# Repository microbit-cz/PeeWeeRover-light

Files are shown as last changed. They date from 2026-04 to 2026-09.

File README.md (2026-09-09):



# PeeWee Rover Light
Jednoduché a levné PeeWee vozítko pro Micro:bit. Jedná se o OpenHardware platformu vyvinutou pro podporu projektové výuky v předmětech jako Programování, Algoritmizace, Informatické myšlení a podobně.

Bez dalších modifikací je vozítko určeno pro programování pomocí MakeCode (Blockly / Static TypeScript) s mikrokontrolérem Micro:bit, lze jej ale snadno adaptovat i na libovolný jiný mikrokontrolér (Arduino, ESP32 atd.).

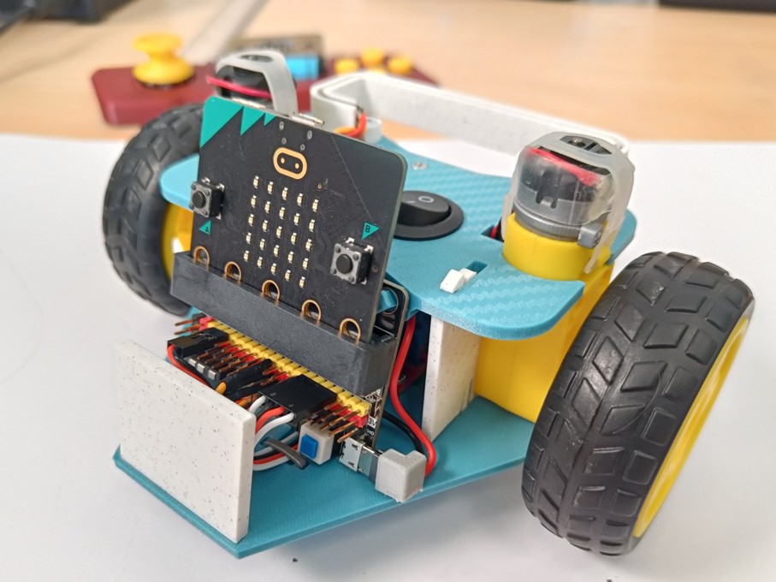
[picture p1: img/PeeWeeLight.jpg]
Foto prototypu


## O projektu
Systém je navržen s ohledem na:
- **Mechanickou robustnost**.
- **Opakovatelnost stavby:** Dražší komponenty je možné používat opakovaně. Levné položky, jako jsou 3D tištěné díly a kabely, stojí řádově desetikoruny. Další studenti tak mohou stavbu bez potíží opakovat od výchozího stavu z rozložených součástek.
- **Mezipředmětové vazby:** Ideální pro propojení oborů jako polytechnika, algoritmizace, elektrotechnika, fyzika, multimédia, matematika a další.

## Hardware a konstrukce
Základem je 3D tištěné šasi, které je osazené dvěma DC130 motory s TT převodovkou, dvěma koly a zadním vláčeným kolečkem (ocelová kulička otočná v 360°). 

Napájení je zajištěno z 2S 7,4V battery packu. Jako zdroj napájení a řízení motorů slouží modul motor driver L298N. Pro řízení logiky je použit Micro:bit připojený do desky IObit pro snadnější propojení GPIO z mikrokontroléru.

**Osvětlení (WS2812B):**
Na vozítku je připevněno celkem 9 adresovatelných RGB LED diod.
- 5 směřuje dozadu (B - Back)
- 1 směřuje vlevo (L - Left)
- 1 směřuje vpravo (R - Right)
- 2 směřují vpřed (F - Front)

Fyzické řazení diod v sérii je: **F - R - B - B - B - B - B - L - F**

## Schéma a návod ke stavbě
- **Zjednodušené schéma elektrického zapojení:** [schema.svg](schema.svg) (nebo [schema.pdf](schema.pdf))
- **Videonávod ke stavbě:** Vzhledem k aktualizacím je k dispozici na stálém přesměrování [https://go.pslib.cz/buildpeewee](https://go.pslib.cz/buildpeewee)

## Metodia a další materiály v českém jazyce
- https://go.pslib.cz/peeweedata

## Software / Programování
Ovládací knihovna (rozšíření) pro prostředí MakeCode je k dispozici v repozitáři: 
[https://github.com/microbit-cz/pxt-peewee-light](https://github.com/microbit-cz/pxt-peewee-light)

## Podklady pro výrobu
Data pro 3D tisk: [PeeWeeLight.3mf](model/PeeWeeLight.3mf)

Referenční sestava: [PeeWeeLightAssembly.stl](model/PeeWeeLightAssembly.stl) 

## Obrázky
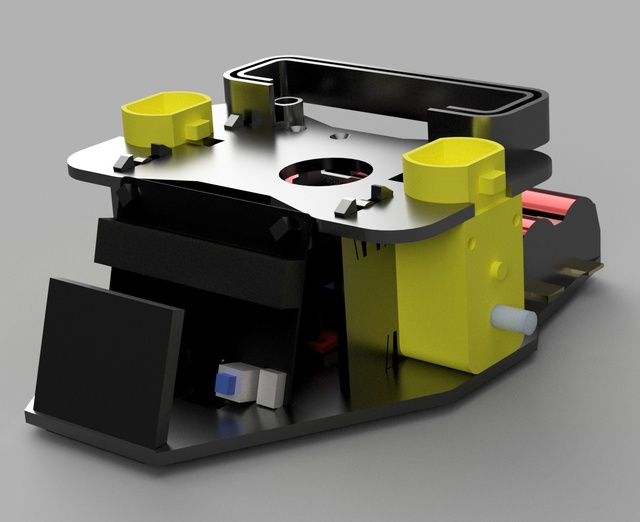
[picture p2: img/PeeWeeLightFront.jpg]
Pohled zepředu


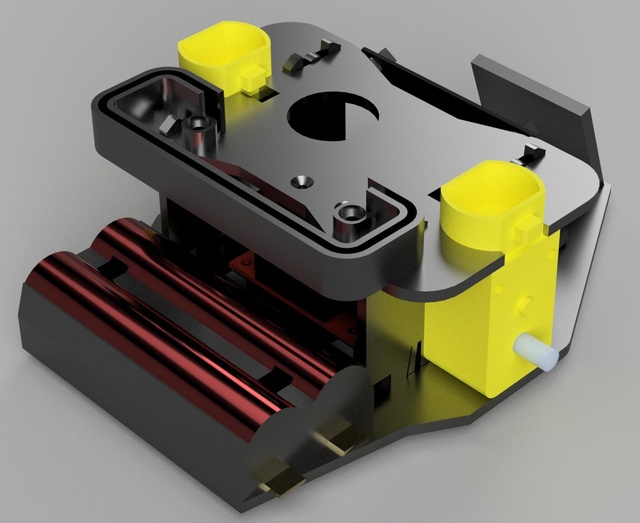
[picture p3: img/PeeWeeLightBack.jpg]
Pohled zezadu


## Seznam dílů

| Množství | Cena | Díl | Náhled |
|:---:|-----:|-----|:---:|
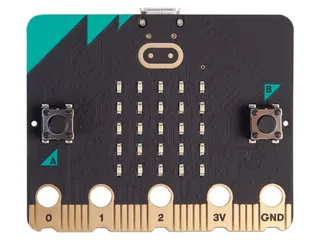
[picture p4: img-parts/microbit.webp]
| 1× | – | [Micro:bit](https://microbit.org/buy/) |  |
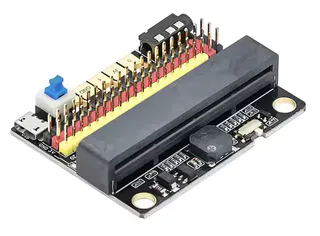
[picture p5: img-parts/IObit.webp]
| 1× | 127 Kč | [IObit V2.0 rozšiřující deska](https://www.aliexpress.com/w/wholesale-microbit-board-IOBIT.html) |  |
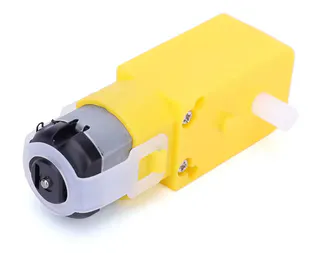
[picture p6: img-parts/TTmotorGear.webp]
| 2× | 73 Kč | [130 DC motor s TT převodovkou 1:48](https://www.aliexpress.com/w/wholesale-TT-gear-motor.html) |  |
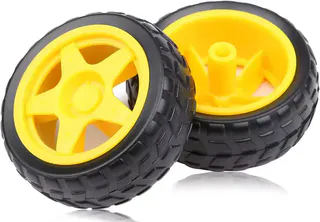
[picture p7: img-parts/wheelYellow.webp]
| 2× | 42 Kč | [65mm žluté kolo](https://www.aliexpress.com/w/wholesale-tt-gear-wheels-65mm.html) |  |
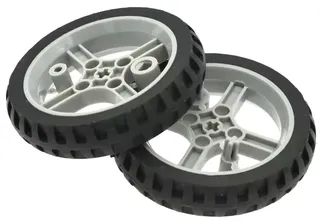
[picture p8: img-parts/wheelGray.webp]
| volitelně 2× | 48 Kč | [65mm šedé kolo 6514 s lepší přilnavostí](https://www.aliexpress.com/w/wholesale-6514-wheel.html) |  |
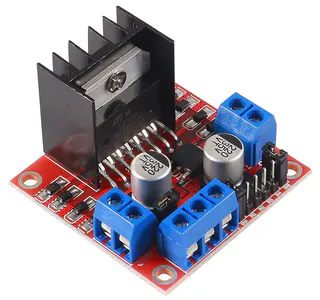
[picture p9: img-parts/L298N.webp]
| 1× | 62 Kč | [L298N H-můstek – ovladač motorů](https://www.aliexpress.com/w/wholesale-L298N-Driver-Board-Module.html) |  |
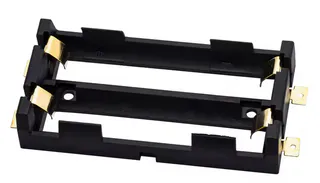
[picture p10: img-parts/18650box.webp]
| 1× | 24 Kč | [18650 2S držák baterií](https://www.aliexpress.com/w/wholesale-18650-battery-holder.html) |  |
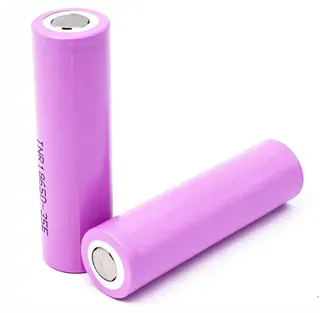
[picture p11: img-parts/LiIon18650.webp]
| 2× | 110 Kč | [18650 baterie](https://www.aliexpress.com/w/wholesale-18650-battery.html) |  |
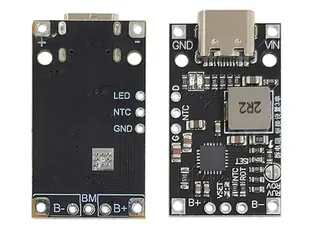
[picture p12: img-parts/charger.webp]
| 1× | 33 Kč | [USB-C 2S BMS nabíjecí modul](https://www.aliexpress.com/w/wholesale-Type%2525252dC-USB-2S-BMS-15W-charger.html) |  |
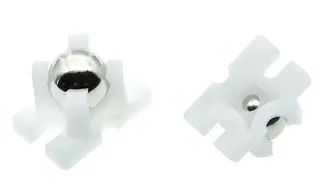
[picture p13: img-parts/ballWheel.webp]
| 1× | 17 Kč | [ocelové kulové otočné kolečko](https://www.aliexpress.com/w/wholesale-Vacuum-W420-Steel-Ball-Universal-Wheel.html) |  |
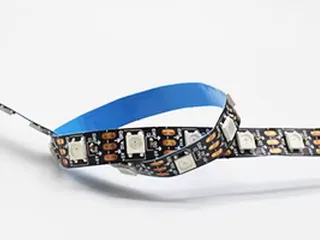
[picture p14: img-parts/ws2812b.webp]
| 9× | 11 Kč | [WS2812B LED (pásek 60 LED/m, IP30)](https://www.aliexpress.com/w/wholesale-WS2812B-60-LED.html) |  |
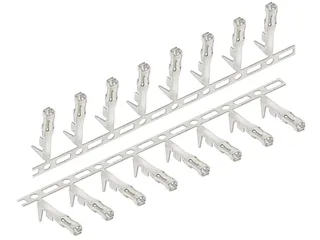
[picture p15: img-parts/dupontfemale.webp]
| 15× | 7 Kč | [Dupont female konektory](https://www.aliexpress.com/w/wholesale-Dupont-2.54mm-TJC8%2525252dT%2525252dD.html) |  |
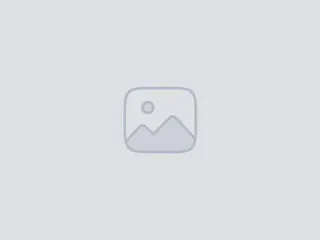
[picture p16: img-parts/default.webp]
| 2× | 1 Kč | [Dupont 4PIN plastové pouzdro 2,54mm](https://www.aliexpress.com/w/wholesale-Dupont-4PIN-plastic-housing-2.54mm.html) |  |
| 1× | 0,50 Kč | [Dupont 2PIN plastové pouzdro 2,54mm](https://www.aliexpress.com/w/wholesale-Dupont-2PIN-plastic-housing-2.54mm.html) |  |
| 1× | 11 Kč | [20cm prodlužovací servo kabel](https://www.aliexpress.com/w/wholesale-20cm-Servo-Extension-Cable-30-core.html) |  |
| – | 15 Kč | [37cm 26AWG silikonový servo kabel](https://www.aliexpress.com/w/wholesale-servo-cable-wire-26AWG-30-Core.html) |  |
| – | 6 Kč | [20cm 20AWG 2PIN silikonový kabel](https://www.aliexpress.com/w/wholesale-20cm-20AWG-Silicone-Wire.html) |  |
| 1× | 11 Kč | [Micro-USB Male 2Pin konektor s připájenými vodiči](https://www.aliexpress.com/w/wholesale-Micro-USB-Male-JACK-2Pin-Welding-Wire.html) |  |
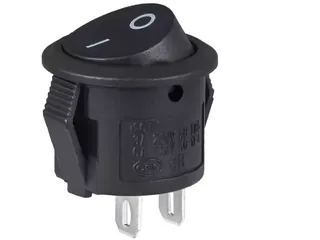
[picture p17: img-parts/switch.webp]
| 1× | 6 Kč | [20mm kulatý kolébkový vypínač snap-in](https://www.aliexpress.com/w/wholesale-round-snap%2525252din-mini-Rocker-Switch.html) |  |
| 6× | 2 Kč | [stahovací pásek 3×100mm](https://www.aliexpress.com/w/wholesale-Self%2525252dLocking-Zip-Ties-3x100.html) |  |
| – | 2 Kč | [smršťovací bužírka 2mm/3mm](https://www.aliexpress.com/w/wholesale-heatshrink-tube.html) |  |
| 6× | 4 Kč | [šroub M3×6mm PH DIN 7985](https://eshop.killich.cz/detail/sroub-m3x6-zinek-4-8-pulkulata-hlava-krizova-drazka-ph-din-7985) |  |
| 6× | 4 Kč | [šroub do plastu 2,2×5mm](https://eshop.killich.cz/detail/sroub-do-plastu-2-2x5-f-zinek-pulkulata-hlava-krizova-drazka-pz-tupy-plasfast-30) |  |

*Celková cena:* cca 570 Kč (bez micro:bitu a dílů pro 3D tisk)

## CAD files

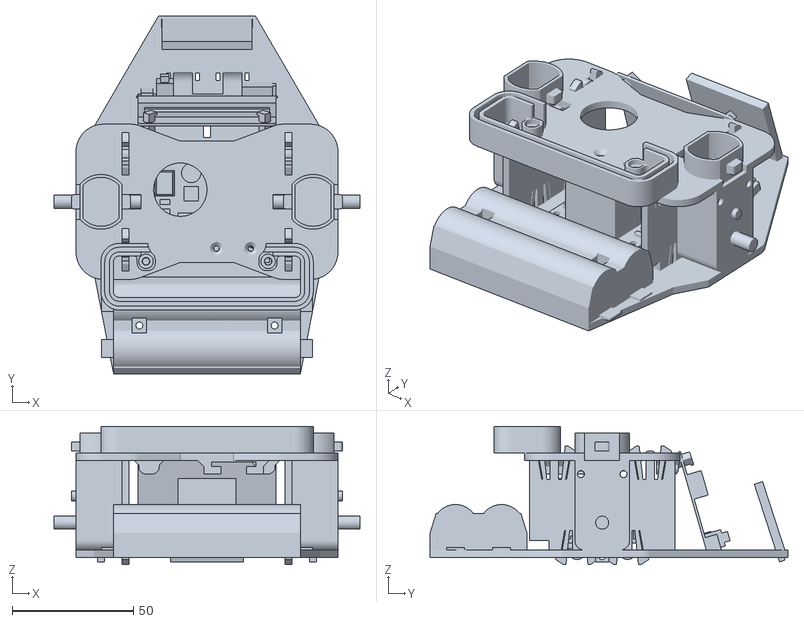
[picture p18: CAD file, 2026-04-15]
model/PeeWeeLightAssembly.stl
126.0 x 147.6 x 57.0

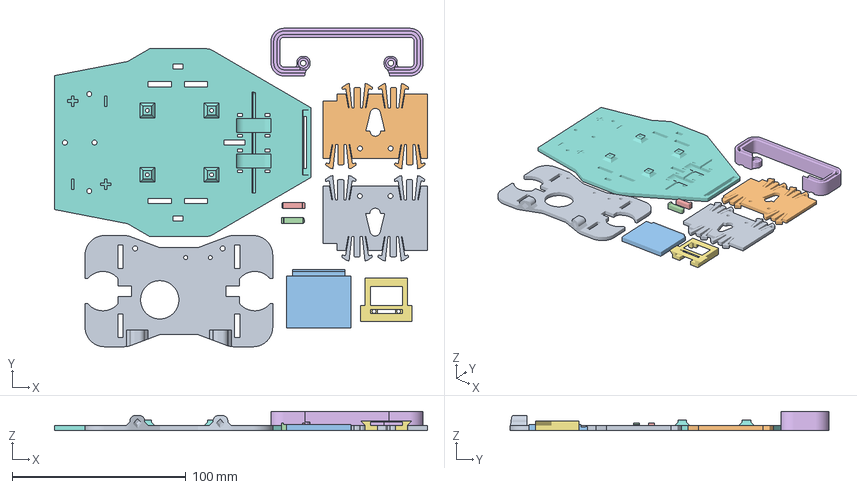
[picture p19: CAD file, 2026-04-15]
model/PeeWeeLight.3mf
214.5 x 183.2 x 11.0 mm
SideLeft
SideRight
Bumper
Pin1
Pin2
LedHolder
PeeWeeLight_2
BottomPlate
PeeWeeLight_1

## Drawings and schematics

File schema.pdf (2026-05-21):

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

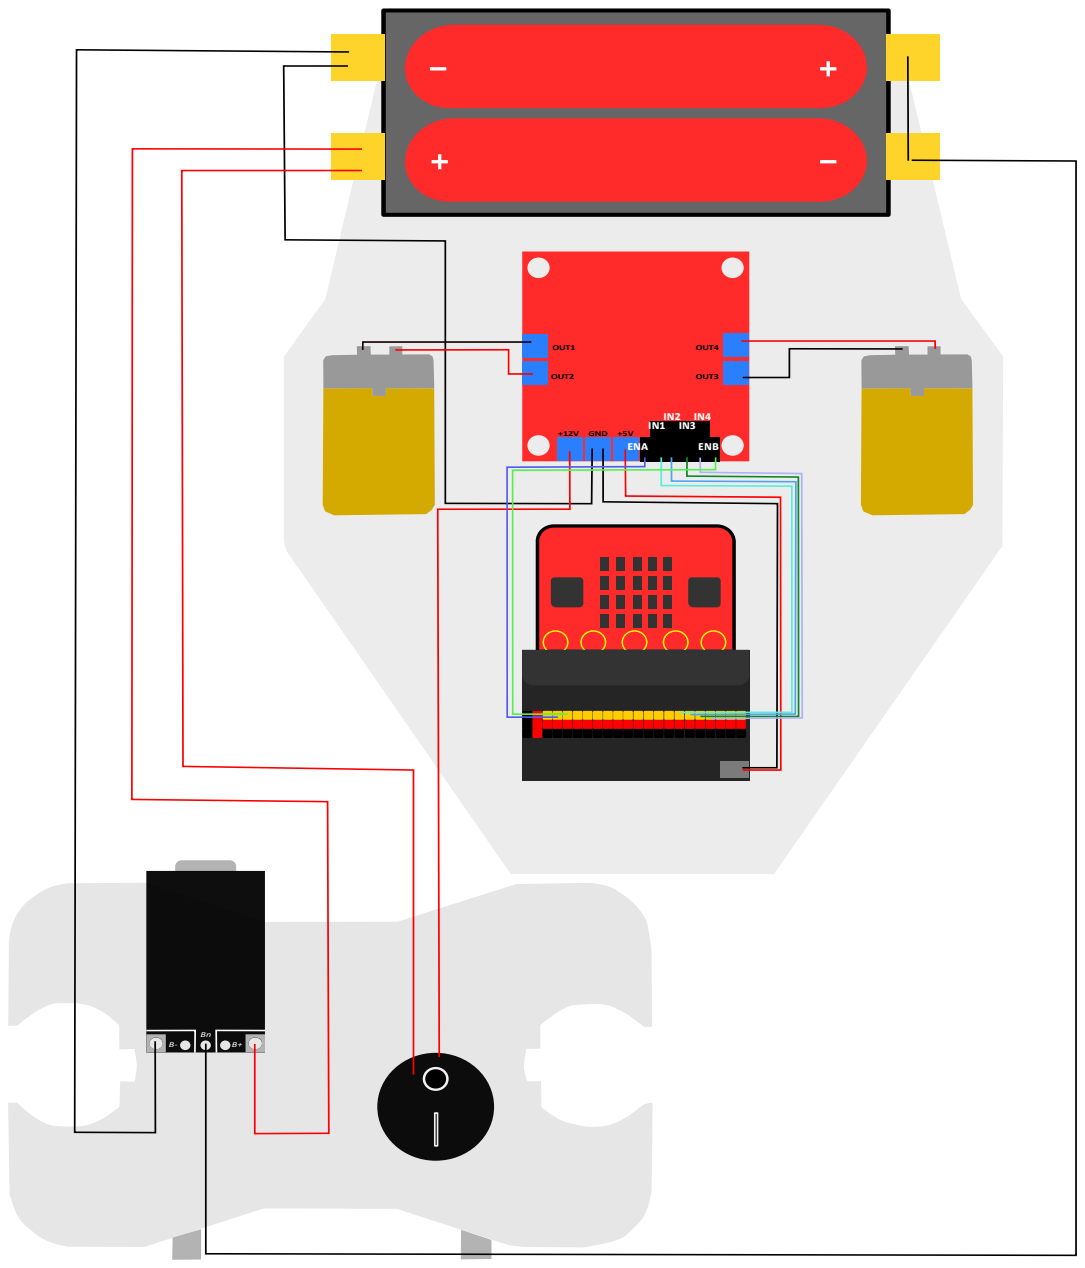
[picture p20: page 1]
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

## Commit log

2026-04-15 raw data
    [PeeWeeLight.3mf, PeeWeeLightAssembly.stl]
2026-09-09 Update README with new methodology section
    Added a section for methodology and additional materials in Czech.
